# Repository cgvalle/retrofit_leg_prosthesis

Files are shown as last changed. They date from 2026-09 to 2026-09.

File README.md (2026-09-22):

# Retrofit Leg Prosthesis: EMG-controlled active add-on for a passive transfemoral prosthesis



Open hardware and software for a **retrofit module that gives a passive prosthetic knee (Ottobock 3R15) active flexion and extension**, driven by surface EMG from the residual limb.

This repository accompanies the manuscript *"From Passive to Active: An EMG-Controlled Add-On Module for Transfemoral Prostheses"*. It contains everything needed to rebuild the prototype that raced at the **CYBATHLON 2024 Powered Leg Prosthesis Race**.

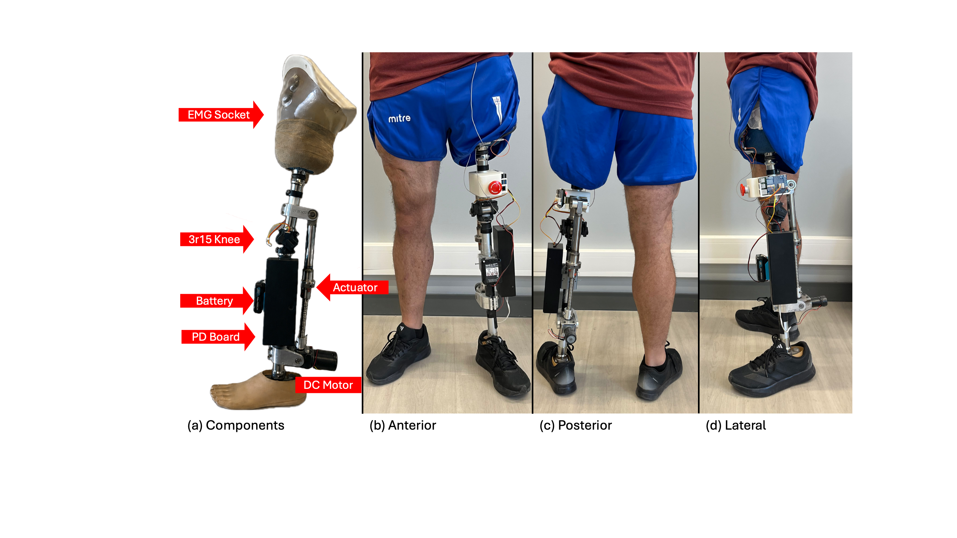
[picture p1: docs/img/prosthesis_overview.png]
Prosthesis overview


> [!WARNING]
> This is a **research prototype, not a medical device**. It was built and tested with a single user under supervision. It has no regulatory approval and must never be used without trained personnel, a reachable emergency stop and a clinician responsible for the socket fit. Read [docs/08_safety.md](docs/08_safety.md) before powering the motor.

## How it works

| Subsystem | Implementation |
|---|---|
| Host prosthesis | Ottobock 3R15 monocentric knee; the user's existing socket, pylons and foot are kept |
| Actuator | 12 V brushed DC worm-gear motor (5840-31ZY, 31:1) driving an SFU1610 ball screw (lead 10 mm) between thigh and shank attachment points. The worm gear is self-locking, so the knee holds its angle without power |
| Power | 12 V 1.5 Ah Li-ion pack (Makita 12 V max) → custom Power Distribution Board (LTC3780 12 V rail, LM2596 5 V rail, BTS7960 H-bridge, E-stop relay) |
| Sensing | 4-channel surface EMG (biceps femoris, rectus femoris, gluteus medius, adductor longus) with electrodes embedded in the socket, OpenBCI Cyton at 250 Hz; AS5600 magnetic encoder for the knee angle |
| Compute | One Raspberry Pi 4 runs everything: acquisition, filtering, Random-Forest intent classifier, knee-angle reference and the 100 Hz PID loop. The processes talk over a local MQTT broker (nanomq) |
| Control | Contraction → the knee reference flexes 5°; relaxation → it extends 5° (10 Hz, range 0–85°, 0 = extended). A predefined gait-pattern mode is also available |

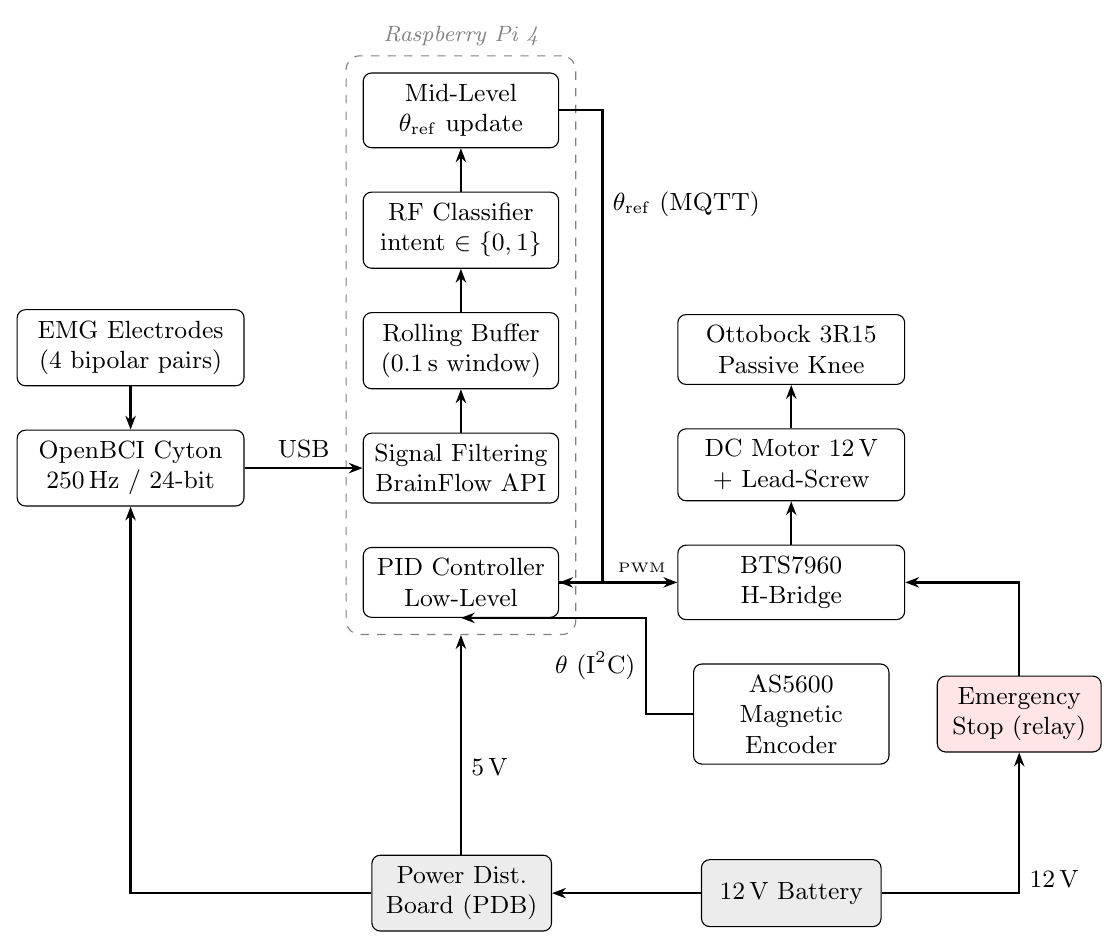
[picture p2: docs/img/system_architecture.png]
System architecture


## Repository layout

```
├── docs/                    Step-by-step build and operation guides (start here)
├── hardware/
│   ├── mechanical/          CAD (STEP / STL / Inventor), renders, motor-torque sizing
│   └── electronics/pdb/     Power Distribution Board: Gerbers, EasyEDA sources, BOM, schematic
├── software/                Python package `leg` that runs on the Raspberry Pi
│   ├── leg/io/stream.py             OpenBCI → filtered EMG → MQTT
│   ├── leg/models/train.py          Train the contract/relax Random Forest
│   ├── leg/models/realtime_inference.py   EMG-driven knee control
│   ├── leg/models/gait_csv_sender.py      Predefined gait-pattern control
│   ├── leg/models/motor_pid.py      AS5600 + BTS7960 PID position loop
│   ├── estimulos/test.py            Cue sequence for recording training data
│   └── test_code/                   Bench tests for motor, encoder and PID
└── analysis/                Metabolic-cost analysis notebook
```

## Build guide

1. [Bill of materials](docs/01_bill_of_materials.md)
2. [Mechanical build](docs/02_mechanical_build.md): mount the ball-screw actuator on the 3R15 knee
3. [Electronics](docs/03_electronics.md): fabricate and bring up the PDB, wire the Pi, motor, encoder and E-stop
4. [Raspberry Pi setup](docs/04_raspberry_pi_setup.md)
5. [EMG socket and acquisition](docs/05_emg_acquisition.md)
6. [Training the intent classifier](docs/06_training.md)
7. [Running the controller](docs/07_control.md)
8. [Safety checklist](docs/08_safety.md)
9. [Experimental protocol (metabolic evaluation)](docs/09_experimental_protocol.md)
10. [Known limitations and roadmap](docs/10_limitations_and_roadmap.md)

## Quick start (software only, no hardware)

```bash
cd software
python -m venv .venv && source .venv/bin/activate
pip install -r requirements.txt && pip install -e .
docker compose up -d                        # MQTT broker (nanomq) on localhost:1883
python -m leg.simulation.synthetic_stream   # BrainFlow synthetic board instead of the Cyton
python -m leg.models.realtime_inference --debug   # classifier only, no motor (needs a model.pkl)
```

## Citation

If you use this work, please cite the paper *"From Passive to Active: An EMG-Controlled Add-On Module for Transfemoral Prostheses"* (under review).

## Funding

Funded by ANID under grant CPS-RTC CIA250016.

## License

MIT: covers the software, hardware design files and documentation, provided "as is". See [LICENSE](LICENSE) and the medical [DISCLAIMER](DISCLAIMER.md).

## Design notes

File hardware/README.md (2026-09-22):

# Hardware

| Folder | Content |
|---|---|
| `mechanical/cad/step` | Machined actuator parts: motor adapter, ball-screw nut adapter, brackets D2/D3 |
| `mechanical/cad/stl` | Ball-screw nut adapter, rail connector, 3D-printed electronics box |
| `mechanical/cad/inventor` | Autodesk Inventor sources for the electronics box (vendor models of the Pi, bearing and button not included) |
| `mechanical/renders` | Preview images of the STL parts |
| `mechanical/sizing` | Motor-torque sizing: Mathematica notebook, PDF printout and Python port (`python torque_calculation.py` reproduces Table 1 of the paper) |
| `electronics/pdb` | Power Distribution Board: Gerbers, EasyEDA sources, BOM, schematic and layout images |

Build instructions: [docs/02_mechanical_build.md](../docs/02_mechanical_build.md) and [docs/03_electronics.md](../docs/03_electronics.md).

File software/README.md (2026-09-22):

# Software: `leg` package

Runs on a Raspberry Pi 4. Setup: [docs/04_raspberry_pi_setup.md](../docs/04_raspberry_pi_setup.md).

```bash
docker compose up -d                          # MQTT broker (nanomq)

python -m leg.io.stream                       # OpenBCI Cyton -> filtered EMG -> MQTT "data"
python -m leg.simulation.synthetic_stream     # same, from the BrainFlow synthetic board (no hardware)
python -m leg.plots.stream_plot               # live EMG plot

python -m leg.io.store_stream                 # record to recordings/<name>.npy
python -m estimulos.test                      # relax / contract cue sequence for training data
python -m leg.models.train <name> [<name> ...]   # train -> model.pkl

python -m leg.models.realtime_inference       # EMG-driven knee control (--debug: no motor)
python -m leg.models.gait_csv_sender          # predefined gait-pattern control (--debug: no motor)
```

| Path | Purpose |
|---|---|
| `leg/parameters.py` | MQTT host (`LEG_BROKER_HOST`), channel layout, sample rate |
| `leg/io/stream.py` | Cyton configuration, stateful 20–120 Hz band-pass + 50 Hz notch, auto-reconnect |
| `leg/models/features.py` | 9 features per channel (RMS, VAR, kurtosis, skewness, ZC, Hilbert-envelope mean/std/max/min) |
| `leg/models/split.py` | Windowing (25 samples) and train/test split |
| `leg/models/motor_pid.py` | AS5600 reading, encoder calibration, PID, BTS7960 drive (GPIO 13 / 18) |
| `test_code/` | Stand-alone bench tests for the encoder, motor direction, PWM and PID |
| `knee_angle_gait*.csv` | Reference trajectories for gait-pattern mode |

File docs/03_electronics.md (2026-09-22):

# 3. Electronics

## Power Distribution Board (PDB)

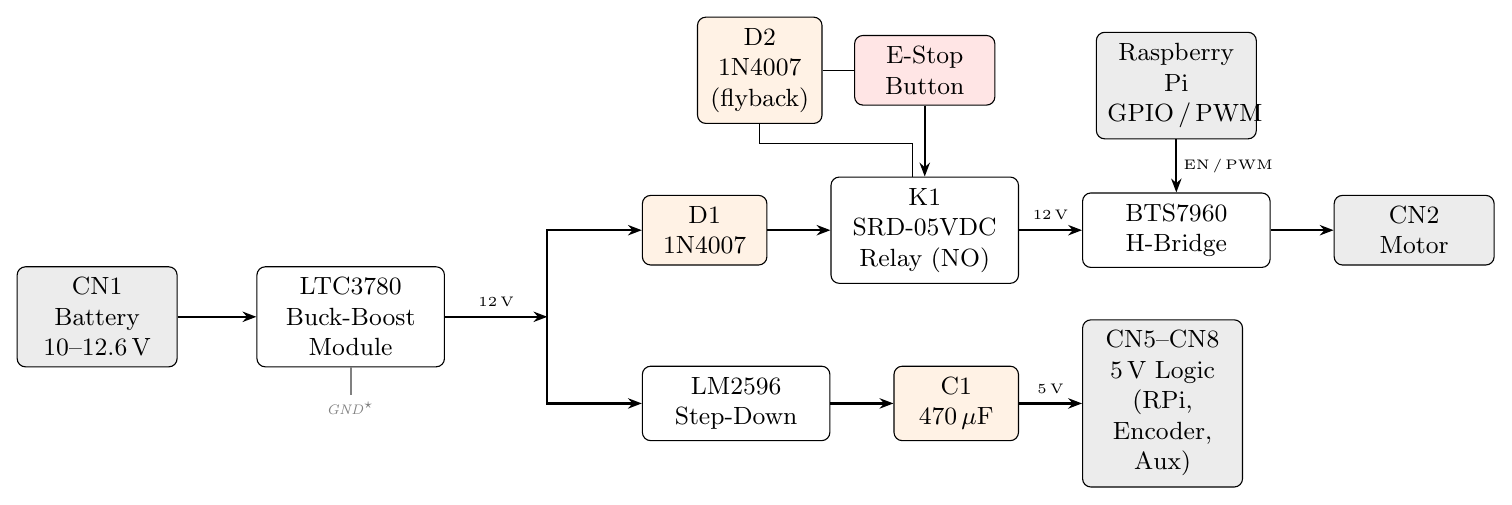
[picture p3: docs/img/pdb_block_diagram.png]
PDB block diagram


The PDB is a two-layer carrier board for off-the-shelf modules:

- **U1, LTC3780 buck-boost.** Turns the 10–12.6 V battery into a regulated **12 V** rail for the motor.
- **U2, LM2596 buck.** Steps the regulated 12 V down to the **5 V** logic rail (Raspberry Pi, encoder, BTS7960 logic).
- **U4, BTS7960 H-bridge.** Drives the motor (43 A peak; the board is operated at 5 A or less).
- **RLY1, SRD-05VDC relay.** Normally-open contact in the 12 V motor path. The E-stop button (CN9) opens it, which cuts motor power while the Pi stays on.
- **Protection.** 1N4007 flyback diode on the relay coil, a 1N4007 series diode on the 12 V motor line, 1 kΩ pull-downs on the PWM/IS lines (safe state at boot) and 1 kΩ pull-ups that keep R_EN/L_EN enabled.
- **Grounding.** Star ground: high-current motor returns and logic returns meet near the battery input.

Files in `hardware/electronics/pdb/`:

| File | Content |
|---|---|
| `gerber/PDB_gerber_2025-09-29.zip` | Fabrication files (upload as-is to JLCPCB or a similar service; 2 layers, 1.6 mm, default options) |
| `easyeda/PDB_schematic.json`, `easyeda/PDB_pcb.json` | Editable sources. In EasyEDA Std: *File → Open → EasyEDA…* and select the JSON |
| `PDB_BOM.csv` | Parts list |
| `PDB_schematic.png`, `PDB_layout_top.png`, `PDB_layout_bottom.png` | Quick-look images |

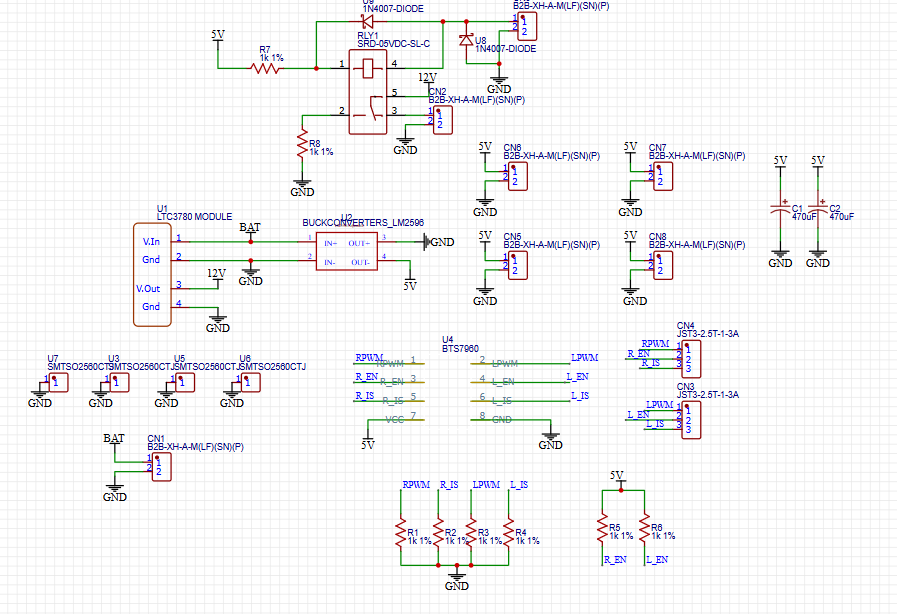
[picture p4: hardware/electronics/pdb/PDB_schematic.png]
PDB schematic


### Connectors

| Connector | Pins | Signal |
|---|---|---|
| CN1 | 1: +BAT, 2: GND | Battery input (10–12.6 V) |
| CN2 | 1: +12 V, 2: GND | Switched 12 V to the H-bridge / motor |
| CN3 | 1: LPWM, 2: L_EN, 3: L_IS | H-bridge control, left half |
| CN4 | 1: RPWM, 2: R_EN, 3: R_IS | H-bridge control, right half |
| CN5–CN8 | 1: +5 V, 2: GND | Logic outputs (Raspberry Pi, encoder, spare) |
| CN9 | 1: BTN IN, 2: BTN OUT | Emergency-stop button (drives the relay coil) |

### Bring-up (do this before connecting the Pi or the motor)

Use a bench supply set to 12 V with a 1 A current limit in place of the battery for steps 1–4.

1. Solder the modules and connectors. Before fitting the modules, check that there is no short between +BAT, +12 V, +5 V and GND.
2. Power CN1. Both module "on" LEDs should light. Adjust the **LTC3780** trimmer until its output reads **12.0 V**. If the output stays off, the undervoltage lock-out has tripped; adjust the trimmer closest to the battery input.
3. Adjust the **LM2596** to **5.0–5.1 V**. Check that the ripple is below 50 mVpp with C1/C2 fitted.
4. Press the E-stop and confirm there is **0 V on CN2**. Release it and confirm 12 V returns.
5. Connect the Raspberry Pi to a 5 V output and confirm it boots without brown-out (no lightning-bolt icon and no `Under-voltage detected` in `dmesg`).
6. Connect the H-bridge and the motor **with the actuator decoupled from the knee**, or with the knee held at mid-range. Run `software/test_code/motor_direction.py` and confirm both directions.
7. Load the motor at about 1 A and record the 12 V droop and module temperatures. Keep an eye on the BTS7960 heatsink.

## Wiring to the Raspberry Pi

| Signal | Pi pin (BCM) | Physical pin | Goes to |
|---|---|---|---|
| Motor PWM (20 kHz), **flexion** | GPIO 18 | 12 | H-bridge input that flexes the knee (RPWM or LPWM, whichever gives flexion on your build) |
| Motor PWM (20 kHz), **extension** | GPIO 13 | 33 | The other H-bridge input |
| I²C SDA | GPIO 2 | 3 | AS5600 SDA |
| I²C SCL | GPIO 3 | 5 | AS5600 SCL |
| 5 V in | — | 2 / 4 | PDB CN5 |
| GND | — | 6 | PDB CN5 GND (common with H-bridge GND) |
| USB | — | USB-A | OpenBCI RF dongle |

These pins are the ones in `software/leg/models/motor_pid.py` (`IN1 = 13`, `IN2 = 18`). A positive controller output (target angle above the measured angle, i.e. flex more) drives GPIO 18. If your knee moves the wrong way, swap the two PWM wires or the two motor leads. Do not swap the pins in software.

> [!CAUTION]
> The Pi's I²C lines are **3.3 V**. Many AS5600 breakouts have pull-up resistors to their own VCC. If you power the encoder from the 5 V rail, SDA and SCL will be pulled to 5 V. Either power the AS5600 from the Pi's **3.3 V** pin (physical pin 1) or remove the breakout's pull-ups.

## System wiring

System architecture

- The OpenBCI Cyton sends its data to the Pi through its USB RF dongle. In the paper's build it is powered from the PDB 5 V rail. The CYBATHLON 2024 build used a separate 6 V battery pack instead, which keeps the EMG front-end isolated from the motor supply; consider it if you see motor noise in the EMG.
- Keep the EMG leads away from the motor cables and the BTS7960. Intermittent drop-outs of the EMG stream were the most common failure seen during testing; connectors, cable routing and shielding all matter.

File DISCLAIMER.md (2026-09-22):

# Disclaimer

The MIT license in [LICENSE](LICENSE) covers the entire repository: software, hardware design files (CAD, PCB, BOM) and documentation.

This is a research prototype and **not a medical device**. It has no regulatory approval. Anyone who builds, modifies or uses it does so at their own risk. It must not be used on a person without trained supervision, a qualified prosthetist, an accessible emergency stop and appropriate ethics approval.

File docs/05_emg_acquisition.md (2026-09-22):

# 5. EMG socket and acquisition

## Muscles and channels

| Cyton channel | Muscle | Role |
|---|---|---|
| C1 | Biceps femoris (hamstrings) | Posterior thigh |
| C2 | Rectus femoris (quadriceps) | Anterior thigh |
| C3 | Gluteus medius | Hip abductor |
| C4 | Adductor longus | Hip adductor |

These are two agonist–antagonist pairs, one at the knee and one at the hip, that stay accessible after transfemoral amputation. In the paper's classifier, envelope features from **C3 (gluteus medius)** carried the most information.

## Electrode placement in the socket

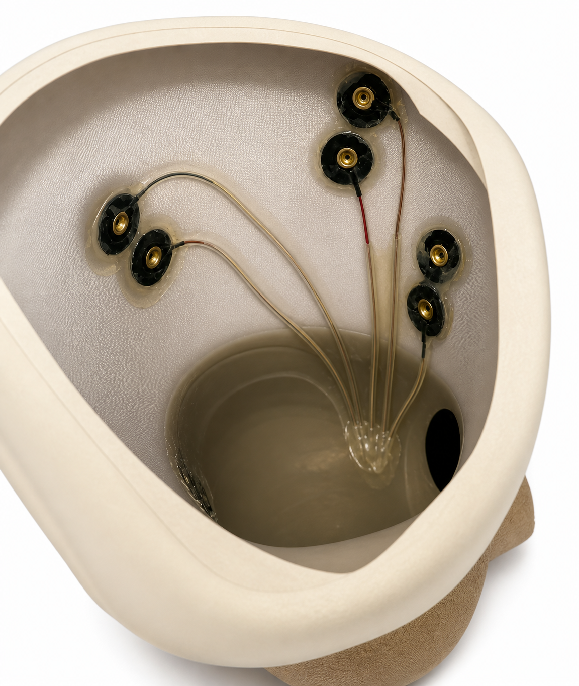
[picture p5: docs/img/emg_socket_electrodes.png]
Electrode placement


1. The clinical team finds the muscle bellies on the residual limb **before the socket is fabricated**.
2. For each muscle, embed two **gold cup electrodes** in the inner wall of the socket, **20 mm apart and aligned with the muscle fibres**.
3. Put one common reference electrode over an electrically quiet area at the hip.
4. Route the leads inside the socket wall to one connector on the socket, then to the Cyton.
5. Before every session, clean the skin with alcohol and put conductive paste on each cup.

> The socket must be made by a certified prosthetist. Embedding electrodes changes the socket's inner surface, so check fit and comfort with the user before any powered trial.

## OpenBCI configuration

`leg/io/stream.py` configures the Cyton at start-up through BrainFlow:

- **Bipolar** montage: gain ×24 (`gain_set=6`), normal electrode input, bias on, SRB2 off, SRB1 off.
- The serial port is auto-detected (the only `usb` device). Override it with `--serial-port /dev/ttyUSB0`.

Wiring:

| Electrode | Cyton pin |
|---|---|
| Muscle *n* (n = 1–4), electrode pair | Channel *n* **N** (bottom) and **P** (top) pins |
| Common reference at the hip | **BIAS** pin |

See the [OpenBCI Cyton documentation](https://docs.openbci.com/Cyton/CytonLanding/) for the header layout.

## Real-time filtering and features

`leg/io/stream.py` reads the board every 32 ms, removes a constant 2250 offset, and filters each EMG channel with **stateful** SOS filters, so block boundaries leave no artefacts:

- 4th-order Butterworth band-pass, **20–120 Hz**
- IIR notch at **50 Hz**, Q = 30 (change `self.mains` to 60 in countries with 60 Hz mains)

The filtered block goes out on the MQTT topic `data`. Features are then computed per 0.1 s window by `leg/models/features.py` (see [06](06_training.md)). If the packet counter stops advancing for 20 consecutive reads, the stream releases and re-opens the BrainFlow session. This recovers from the intermittent dongle drop-outs seen in testing.

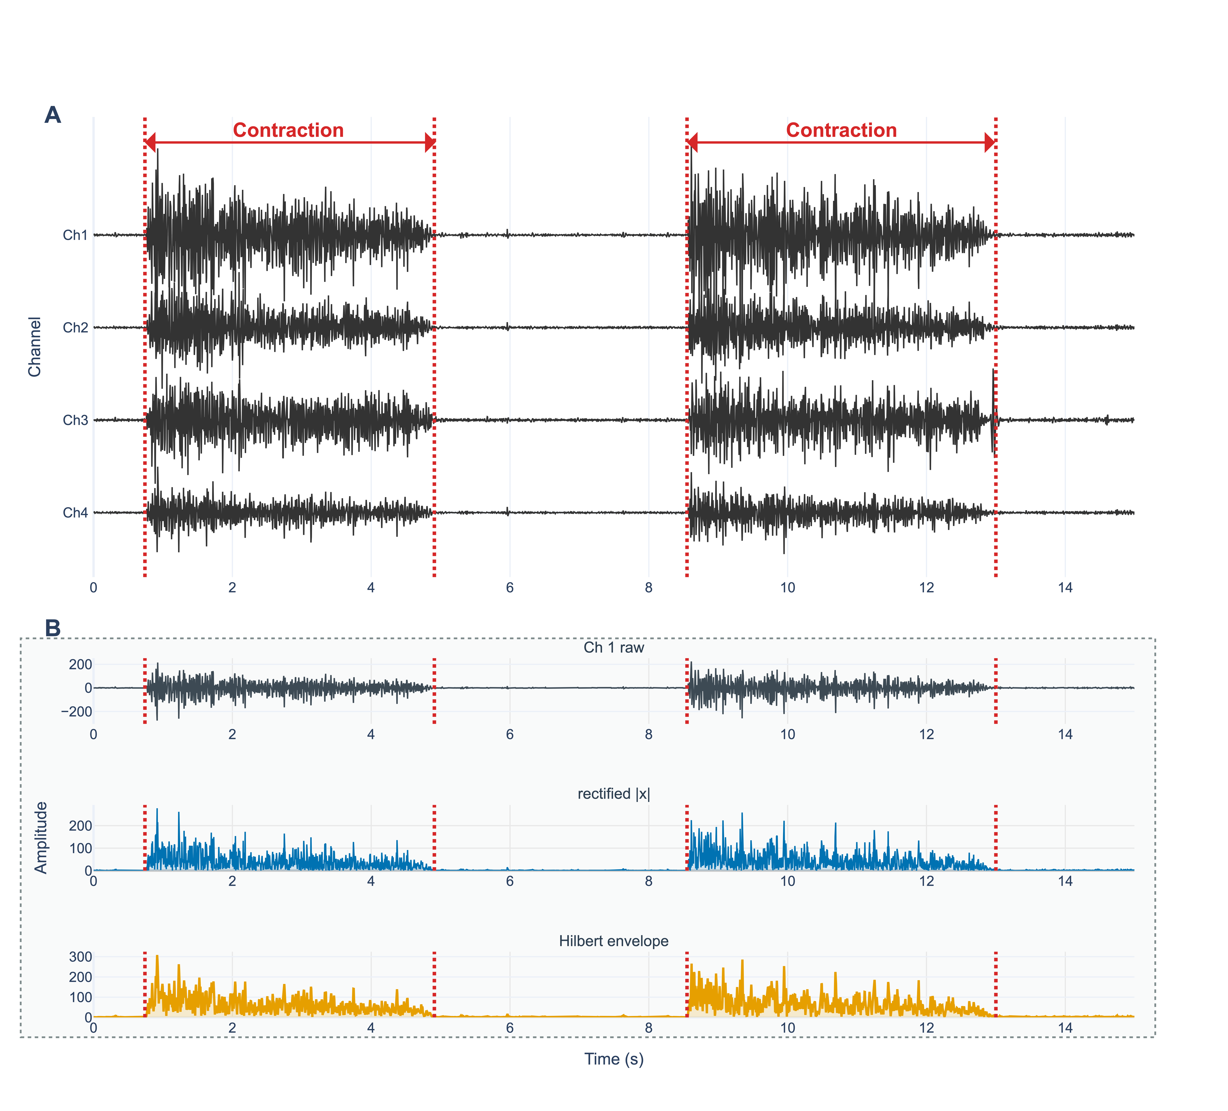
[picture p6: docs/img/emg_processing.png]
EMG processing


## Checking the signals

On a laptop on the same network:

```bash
export LEG_BROKER_HOST=retrofit-leg.local
python -m leg.plots.stream_plot
```

Ask the user to contract and relax. All four channels should show clear bursts. A flat or 50 Hz-dominated channel means poor contact; re-apply the paste or check the lead.

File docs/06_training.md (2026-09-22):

# 6. Training the intent classifier

The controller needs a binary classifier: **0 = relaxed**, **1 = voluntary contraction**. Train it for each user, and retrain whenever the electrodes are repositioned.

## 1. Record labelled data

Three terminals on the Pi, with the user seated and wearing the socket:

```bash
# Terminal 1: EMG stream
python -m leg.io.stream

# Terminal 2: recorder (asks for a file name, press q + Enter to stop)
python -m leg.io.store_stream          # e.g. name: user01_session01

# Terminal 3: cue sequence
python -m estimulos.test
```

`estimulos/test.py` publishes markers on the `marker` topic, and the stream writes them into the recording's marker channel:

- It starts with marker **0** (idle), then shows a 4 s countdown.
- Then come **20 trials of 4 s**, alternating **"Relaja!" (relax, marker 1)** and **"Contrae!" (contract, marker 2)**. The prompt is shown on screen; translate the strings in `estimulos/test.py` if needed.
- It ends with marker **0**.

Stop the recorder after the "Fin del experimento" message. The file is saved as `recordings/<name>.npy` with shape `(14, samples)`: EMG C1–C8, accelerometer, time, packet counter, marker.

Record several sessions: different days, and seated as well as standing. Trials recorded only while seated generalise poorly to walking.

## 2. Train

```bash
python -m leg.models.train user01_session01 user01_session02
```

`leg/models/train.py` then does the following:

1. Keeps samples with marker 1 or 2, and maps 2 → class 1 (contraction) and 1 → class 0 (rest).
2. Cuts channels **C1–C4** into non-overlapping **0.1 s windows (25 samples)**. 20 % of the windows are held out at random for testing (seed 42).
3. Extracts **9 features per channel, 36 in total**, with `leg.models.features_v1`: RMS, variance, kurtosis, skewness, zero-crossings, and the mean, standard deviation, max and min of the Hilbert envelope. Windows with invalid (NaN or inf) features are removed.
4. Fits a pipeline: **feature normalisation** (z-score) → **ANOVA F-score selection of the top 10 features** (`--k` to change) → **Random Forest**. The forest's hyperparameters are tuned by grid search (`n_estimators` 10–100, `max_depth` None/10/20, `min_samples_split` 2/5; 3-fold CV).
5. Prints the cross-validation and held-out accuracy, the confusion matrix, per-class precision/recall/F1, and the selected features ranked by importance.
6. Saves the whole pipeline to **`model.pkl`** in the current directory. It takes all 36 features as input, so the controller needs no changes when `--k` changes.

Run the controller from the same directory so it finds `model.pkl`.

## Expected performance

On the paper's pilot, 645 training and 161 test windows gave:

| | Predicted rest | Predicted contraction |
|---|---|---|
| True rest | 68 | 17 |
| True contraction | 10 | 66 |

That is **83.2 % accuracy**, with contraction precision 0.80, recall 0.87 and F1 0.83. Accuracy was 84.9 % on steady windows but only 55.6 % on windows at a rest↔contraction transition. Keeping the top 10 features gave 83.7 % cross-validation accuracy, against 84.7 % with all 36. Performance plateaus at about 10 features, and envelope-amplitude features from C3 (gluteus medius) dominate the selection.

If you get well below about 80 %, check electrode contact first (see [05](05_emg_acquisition.md)). Then check that the user is making a clear, repeatable contraction rather than a small one.

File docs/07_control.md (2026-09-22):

# 7. Running the controller

The control stack has three layers. Both operating modes share the same low-level loop.

```
High level  (10 Hz)   EMG window → features → Random Forest → intent ∈ {0, 1}
Mid level   (10 Hz)   intent → knee-angle reference θ_ref
Low level   (100 Hz)  PID → sign → BTS7960 at full duty (20 kHz PWM)
```

Knee angles run from **0° (fully extended) to 85° (flexed)**. See the encoder calibration in [04](04_raspberry_pi_setup.md).

## Mode A: EMG-driven intent control

```bash
docker compose up -d                        # broker, if not already running
python -m leg.io.stream                     # terminal 1
python -m leg.models.realtime_inference     # terminal 2 (model.pkl in the working directory)
```

To run the classifier without touching the motor (watch the reference on the `marker` topic), add `--debug`.

What `leg/models/realtime_inference.py` does:

- It keeps a rolling **0.1 s buffer** (25 samples) of C1–C4, fed by the `data` topic.
- Every **100 ms** it extracts the 36 features and passes them to the trained pipeline (normalisation → top-10 selection → Random Forest).
- **Contraction** raises the reference by **5°** (the knee flexes); **relaxation** lowers it by **5°** (the knee extends).
- Because the loop runs at 10 Hz, the reference slew rate is bounded at **50°/s** by construction, so abrupt setpoint changes cannot reach the low-level loop.
- The reference is clipped to **0–85°** and published on `marker` for logging.
- **Ctrl-C** sets the reference to 0° (fully extended) before exiting.

Piloting: the user learns to **contract to bend the knee and relax to straighten it**. Initiate motion *before* it is needed, since the actuator is slow. That anticipatory style worked for the Slopes and Wobbly Steps tasks at CYBATHLON.

## Mode B: predefined gait pattern

```bash
python -m leg.models.gait_csv_sender --speed 0.1 --n-samples 5 --log-csv run.csv
```

This mode plays back a knee-angle trajectory from `knee_angle_gait_short.csv` (default: 0° → 60° → 0°), resampled to `--n-samples` points. It advances one point every `1 / (10 × speed)` seconds and pauses 1.5 s between cycles. Every point is shifted by a hard-coded **−7°** (`angle -= 7`). Remove that line, or adjust the offset, for your build, because a negative target pushes the actuator against full extension. `--log-csv` saves target and measured angle over time. `knee_angle_gait.csv` holds a full normative gait-cycle profile (8–65°) that you can pass with `--csv`.

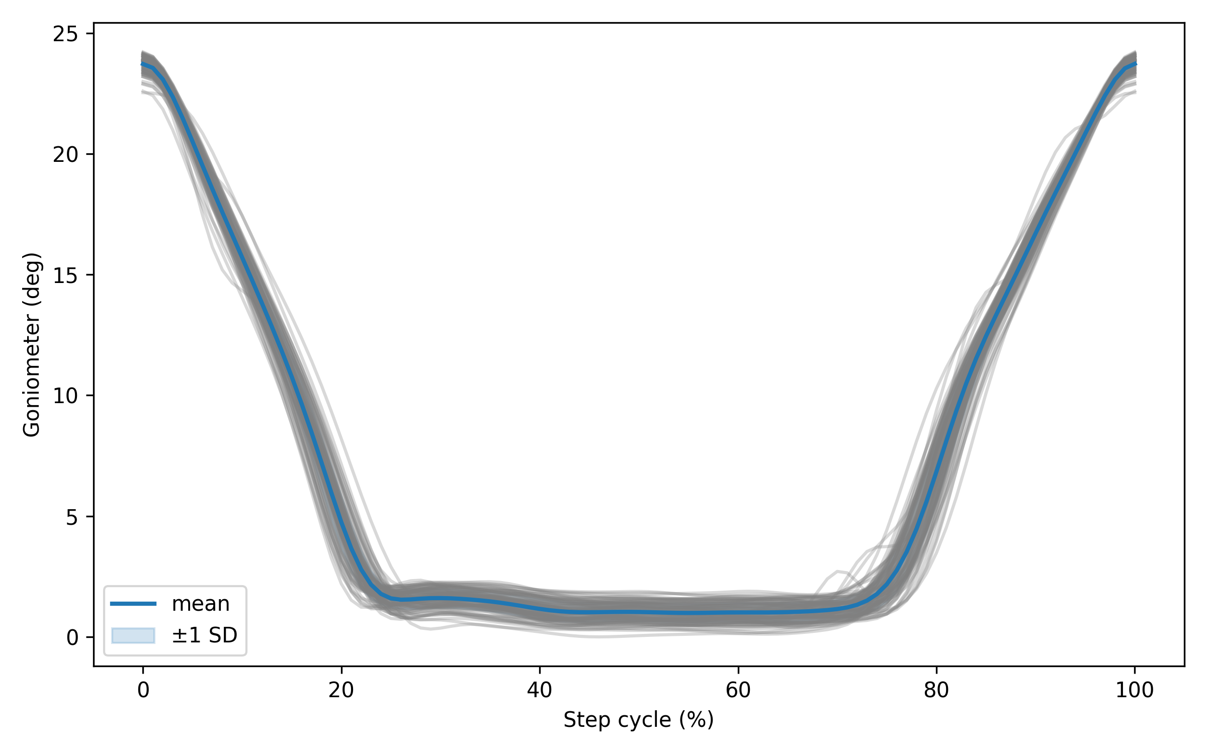
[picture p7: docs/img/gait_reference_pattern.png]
Reference gait pattern


## Low-level loop: `leg/models/motor_pid.py`

- Reads the AS5600 over I²C at **100 Hz** (12-bit, 0.088° per count) and converts it to the knee angle using the calibration constants.
- Discrete PID using the measured sample interval, so scheduling jitter does not bias the I and D terms. The integral is clamped to ±100, and the derivative term is skipped on the first sample after a reset.
- Gains (tuned on the bench): **Kp = 10, Ki = 0.1, Kd = 0.15**. Change them with `MotorPIDController(kp=…, ki=…, kd=…)`.
- **Drive law:** the sign of the PID output selects the direction. A positive output drives GPIO 18 (flexion) and a negative output drives GPIO 13 (extension), at **100 % duty** with **20 kHz PWM**. The other input is held at 0. Because the screw is highly reduced and non-back-drivable, the switching does not reach the joint as abrupt motion. The cost is a small limit cycle around the reference.

## Monitoring

From a laptop: `LEG_BROKER_HOST=retrofit-leg.local python -m leg.plots.stream_plot` shows the EMG channels live, and the marker channel shows the knee reference. `python -m leg.io.store_stream` records everything to `.npy` for later analysis.

## Performance to expect

- Walking assistance works on a treadmill at about **1 km/h**; tracking degrades when the reference changes quickly.
- Stairs, obstacle clearance and high steps were **not** achievable with this actuator and binary control (see [10](10_limitations_and_roadmap.md)).

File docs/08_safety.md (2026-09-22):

# 8. Safety

This device moves a joint that a person is standing on. Treat every powered session as a clinical experiment: get ethics approval, have a prosthetist and an engineer present, and use a harness or parallel bars for early trials.

## Failure behaviour you must know

| Situation | What happens | Mitigation |
|---|---|---|
| E-stop pressed | The relay cuts the 12 V motor supply. The Pi keeps running. **The knee locks at its current angle** (the worm gear is self-locking) | Train the user and the assistant to press it. Test it at the start of every session |
| Battery empty or power lost | Same as the E-stop: the knee locks where it is. The passive 3R15 cannot swing | Check the charge (Makita gauge) before each session; one battery lasts about 2.5 h of walking |
| EMG stream stalls (dongle drop-out) | `leg.io.stream` tries to re-open the session, but **the inference keeps classifying the last buffer**, so the reference can drift to a limit | Watch the live plot and keep the E-stop ready. Adding a watchdog is on the roadmap |
| Control process crashes | Ctrl-C drives the knee to full extension, but an unhandled crash can leave a PWM pin in its last state | Keep the E-stop reachable. Bench-test after every software change |
| Misclassification | Each false prediction moves the reference 5° the wrong way (at most 50°/s) | Start with the prosthesis off the user, then in parallel bars |

## Before every session

- [ ] Battery charged; E-stop tested (0 V on the motor with the button pressed)
- [ ] All actuator fasteners and the screw coupling checked; no play at the nut or supports
- [ ] Encoder reads 0° at full extension and tracks flexion correctly up to 85° (`test_code/encoder.py`)
- [ ] Classifier trained or validated **today** with the electrodes as placed (see [06](06_training.md))
- [ ] Live EMG looks clean on all four channels
- [ ] Controller run in `--debug` mode first: the reference follows contract/relax as expected
- [ ] First motor movements done with the user seated and the foot off the ground

## Electrical

- Use a bench supply with current limiting for the first PDB power-up.
- The BTS7960 can source tens of amps. Watch its temperature under sustained load, and fuse the battery line.
- Li-ion packs: use the original charger, never charge unattended, and keep the pack in its impact-resistant case.

## Mechanical

- The actuator adds about 4 kg, mostly distal, which the user feels during fast leg movements.
- Check the ball screw's travel at both ends. At full extension the nut must not bottom out, because the motor has no end-stop sensing in the current software.

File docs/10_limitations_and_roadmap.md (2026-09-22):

# 10. Known limitations and roadmap

## Limitations of this prototype

- **Actuator authority.** The 5840-31ZY motor gives 0.49 N·m, but level walking needs 0.77–1.53 N·m (`hardware/mechanical/sizing`). Assistance is partial, and fast tasks (stairs, obstacle clearance, high steps, sit-to-stand) are out of reach. At CYBATHLON 2024 only Slopes (both runs) and Wobbly Steps (run 2) were completed.
- **Non-back-drivable transmission.** It holds position without power, but it removes free pendular swing, so all knee motion has to come from the torque-limited motor.
- **Binary intent.** Contract/relax commands only change the reference in steps. There is no proportional control of speed, torque or impedance, and no automatic gait-phase detection.
- **EMG robustness.** Intermittent drop-outs of the OpenBCI stream were seen, with no conclusive cause. The classifier was validated offline on static trials (83.2 %), not during walking.
- **Mass.** The module adds about 4 kg, mostly distal, for a total of about 8 kg.
- **Evidence.** Everything was tested with a single participant.

## Software to-dos

- Watchdog: stop the motor if no EMG packet arrives within about 200 ms.
- End-of-travel protection: stall-current sensing through the BTS7960 `IS` pins, or limit switches.
- Soft-start PWM ramps. The driver currently switches straight to 100 % duty.

## Hardware roadmap (CPS-RTC internal design review, 2026)

- Battery: move from the 3S Li-ion Makita pack (16.2 Wh, 1–2 C) to a 4S LiPo (22.2 Wh, 35 C) with an external BMS and XT60 connector. The LTC3780 then runs in buck mode (≈95–96 % efficiency).
- Motor: a candidate is the maxon RE 30 (60 W, 12 V, 87 % peak efficiency) with a GP32 A planetary gearhead. Its high start-up current (about 61 A) needs a PWM soft start over 30–50 ms, because the 12 V rail is limited to 8–10 A. The review also recommends moving to a BLDC motor with a matching three-phase driver.
- Characterise the torque–speed demand of the knee for each task before choosing the next actuator.
- Mount the motor at the knee to reduce distal mass.
- Environment sensing (2D LiDAR, IMU) for terrain-aware control.

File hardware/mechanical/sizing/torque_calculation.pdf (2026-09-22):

# Cálculos torque-motor para caminata

# 1. Lados triángulos naranjos (fijos)

In[ ]:= a1 = 90;
k1 = 295;
a2 = 50;
k2 = 50;

# 2. Lados triangulo principal

In[ ]:= bmin = 275;
bmax = 385;
k =
raíz cuadrada

Sqrt[k1^2 + k2^2] //
valor numérico

N

a =
raíz cuadrada

Sqrt[a1^2 + a2^2] //
valor numérico

N

Out[]= 299.207

Out[]= 102.956

# 3. Ángulos triángulos naranjos (fijos)

In[ ]:= sola =
resuelve

Solve[a2^2 a1^2 + a^2 - 2 * a1 * a * coseno

Cos[x] && 0 < x <
número pi

Pi, x] //
valor numérico

N

a3 = (x /.
primero

First[sola]) /
grado

Degree //
valor numérico

N

Solve: Solve was unable to solve the system with inexact coefficients. The answer was obtained by solving a corresponding exact system and numericizing the result.

Out[]= {{x 0.507099}}

Out[]= 29.0546

Printed by Wolfram Mathematica Student Edition

In[ ]:= solk =
resuelve

Solve[k2^2 k1^2 + k^2 - 2 * k1 * k * coseno

Cos[x] && 0 < x <
número pi

Pi, x];

k3 = (x /.
primero

First[solk]) /
grado

Degree //
valor numérico

N

Solve: Solve was unable to solve the system with inexact coefficients. The answer was obtained by solving a corresponding exact system and numericizing the result.

Out[]= 9.61973

# 4. Ángulo rodilla máximo con largo husillo mínimo (no usar)

In[ ]:= sol =
resuelve

Solve[bmin^2 a^2 + k^2 - 2 * a * k * coseno

Cos[x] && 0 < x <
número pi

Pi, x] //
valor numérico

N;

beta = (x /.
primero

First[sol]) /
grado

Degree //
valor numérico

N

Solve: Solve was unable to solve the system with inexact coefficients. The answer was obtained by solving a corresponding exact system and numericizing the result.

Out[]= 66.5681

In[ ]:= alfa = 180 - beta - a3 - k3

Out[]= 74.7576

# 5. Ángulo rodilla mínimo con largo husillo máximo

In[ ]:= sol =
resuelve

Solve[bmax^2 a^2 + k^2 - 2 * a * k * coseno

Cos[x] && 0 < x <
número pi

Pi, x] //
valor numérico

N;

beta = (x /.
primero

First[sol]) /
grado

Degree //
valor numérico

N

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

Out[]= 141.326

In[ ]:= alfa = 180 - beta - a3 - k3
Out[]= -4.9738 × 10⁻¹⁴

# 6. Largo husillo con ángulo rodilla literatura (desde acá probar ángulos)

In[ ]:= alfa = 1;

In[ ]:= beta = -alfa + 180 - a3 - k3

Out[]= 140.326

### 2 calculos v2.nb

In[ ]:= sol =
resuelve

Solve[x^2 a^2 + k^2 - 2 * a * k * coseno

Cos[beta °] && x > 0, x] // valor numérico

N;

b = (x /.
primero

First[sol]) //
valor numérico

N

Out[]= 384.117

# 7. Vectores posición

In[ ]:= K = {0, 0, 0};
A = {-a2, a1, 0};
B = {-k2 *
coseno

Cos[alfa °] - k1 *
seno

Sin[alfa °], k2 *
seno

Sin[alfa °] - k1 *
coseno

Cos[alfa °], 0} //
valor numérico

N

Out[]= {-55.1408, -294.082, 0.}

In[ ]:= KA = A - K
KB = B - K
AB = B - A

Out[]= {-50, 90, 0}

Out[]= {-55.1408, -294.082, 0.}

Out[]= {-5.14084, -384.082, 0.}

# 8. Brazo palanca (P = peso, M = momento extensor, r = brazo, F = fuerza)

In[ ]:= c = 0.49;
P = 90.36;

In[ ]:= M = c * P
r =
norma

Norm[
producto vectorial

Cross[KA, KB]] /
norma

Norm[AB] / 1000 //
valor numérico

N

F = M / r

Out[]= 44.2764

Out[]= 0.0512

Out[]= 864.773

# 9. Torque motor (L = paso hilo, e = eficiencia)

In[ ]:= L = 0.01;
e = 0.9;

In[ ]:= T = (F * L) / (2 *
número pi

Pi * e)

Out[]= 1.52925

calculos v2.nb 3

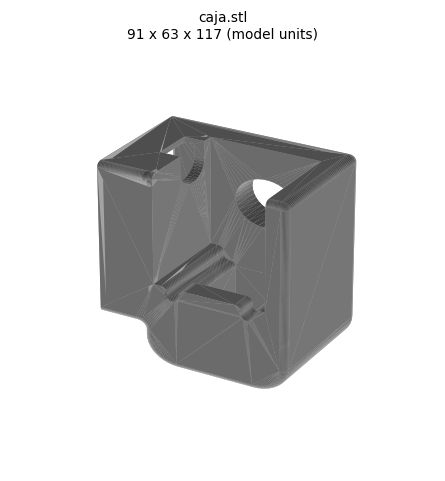
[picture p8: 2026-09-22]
hardware/mechanical/renders/electronics_box.png

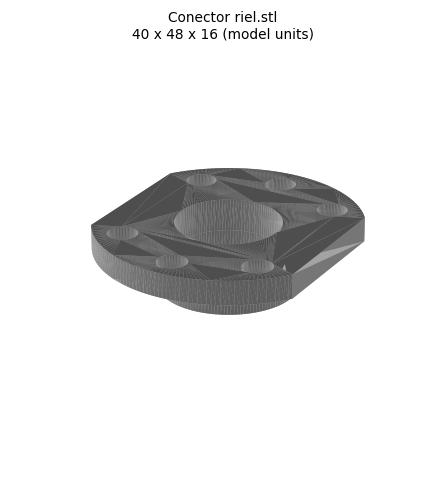
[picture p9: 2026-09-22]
hardware/mechanical/renders/rail_connector.png

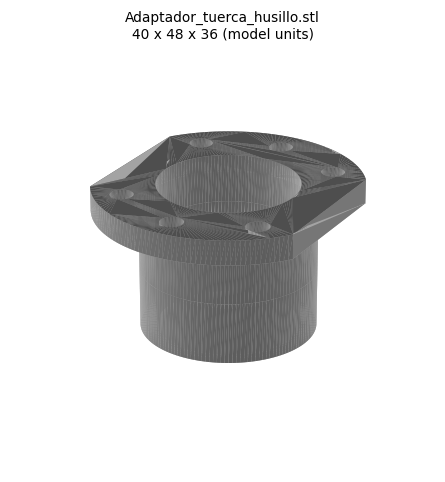
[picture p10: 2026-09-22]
hardware/mechanical/renders/ballscrew_nut_adapter.png

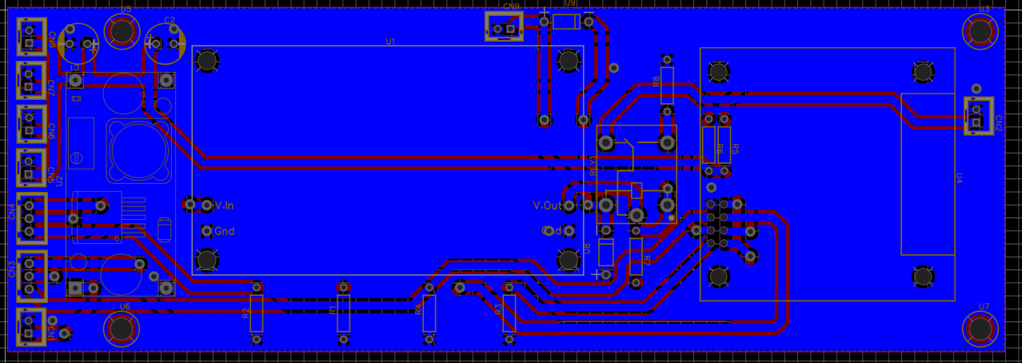
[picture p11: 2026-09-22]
hardware/electronics/pdb/PDB_layout_bottom.png

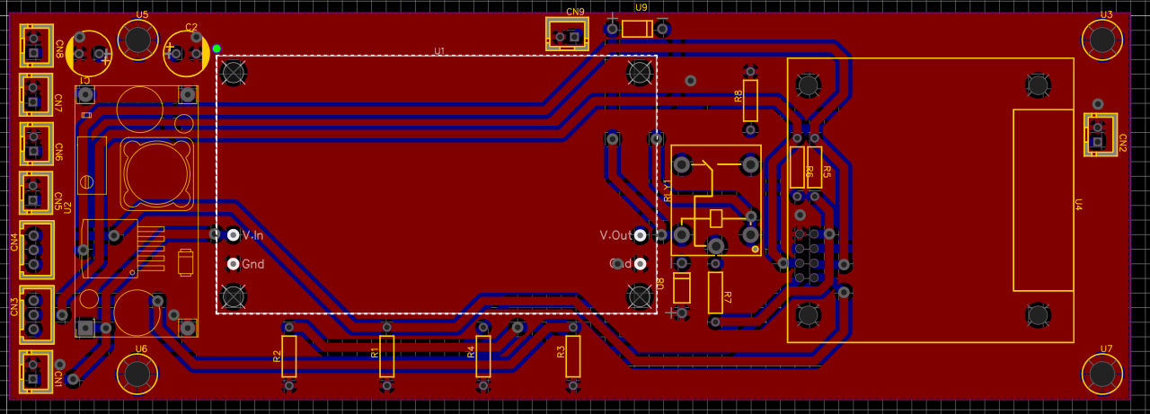
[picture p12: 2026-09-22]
hardware/electronics/pdb/PDB_layout_top.png

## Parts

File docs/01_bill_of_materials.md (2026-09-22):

# 1. Bill of materials

Quantities are for one prosthesis. The table assumes the user already has a prescribed passive prosthesis built around an **Ottobock 3R15** knee. The add-on keeps that socket, knee, pylons and foot.

Items marked **TBD** could not be confirmed from the project records; measure them on your build.

## Host prosthesis (already prescribed to the user)

| Item | Qty | Notes |
|---|---|---|
| Ottobock 3R15 monocentric knee joint | 1 | Steel, 490 g, max. user mass 100 kg, flexion up to 150° |
| Custom socket | 1 | Made by the user's prosthetist. The EMG electrodes are embedded in its inner wall (see [05](05_emg_acquisition.md)) |
| Upper tube / stem | 1 | Aluminium, Ø 32.4 mm, 120 mm long (CYBATHLON 2024 build) |
| Lower tube / stem | 1 | Aluminium, Ø 32.4 mm, 320 mm long (CYBATHLON 2024 build) |
| Prosthetic foot and pyramid adapters | 1 set | Whatever the user already wears |

## Actuator

| Item | Qty | Notes |
|---|---|---|
| Brushed DC worm-gear motor, 12 V, **5840-31ZY**, 200 rpm variant (31:1) | 1 | 0.49 N·m nominal at 200 rpm, 2 A, 364 g. The worm gear is **self-locking**. See the torque note below |
| Ball-screw kit **SFU1610** (Ø16 mm, lead 10 mm, C5) with **BK12** fixed and **BF12** floating supports and a nut | 1 | Sold as a kit, cut to length. The prototype screw spans 294–384 mm between attachment points |
| Shaft coupling, motor → screw | 1 | Set-screw adapter, sized to the motor output shaft |
| Motor adapter (machined) | 1 | `hardware/mechanical/cad/step/motor_adapter.step` |
| Ball-screw nut adapter | 1 | `hardware/mechanical/cad/step/ballscrew_nut_adapter.step` (STL also provided) |
| Rail connector | 1 | `hardware/mechanical/cad/stl/rail_connector.stl` |
| Brackets D2 / D3 | 1 each | `hardware/mechanical/cad/step/D2.step`, `D3.step`, `D3_v2.step` |
| Fasteners (M3–M6), spacers | TBD | Depends on your knee and tube clamps |

> **Torque note.** The installed motor is **under-sized**: level walking needs 0.77–1.53 N·m at the motor shaft (see `hardware/mechanical/sizing/torque_calculation.py`), but the motor gives 0.49 N·m. The prototype therefore provides only partial assistance. If you are rebuilding the device, consider a stronger drive (see [10](10_limitations_and_roadmap.md)).

## Electronics

| Item | Qty | Notes |
|---|---|---|
| Raspberry Pi 4 Model B (2 GB or more) + microSD card (16 GB or more) | 1 | Runs all software |
| OpenBCI Cyton (8-ch, 250 Hz, 24-bit) + USB RF dongle | 1 | Only channels C1–C4 are used for control |
| AS5600 magnetic angle encoder breakout + diametric magnet | 1 | I²C address 0x36, 12-bit |
| Power Distribution Board (PDB) | 1 | Custom PCB. See `hardware/electronics/pdb/PDB_BOM.csv` for its parts (LTC3780, LM2596 and BTS7960 modules, SRD-05VDC relay, etc.) |
| Emergency-stop push button, self-locking (e.g. LAY37 series) | 1 | Wired to PDB connector CN9. Cuts **only** the motor supply |
| Battery: Makita 12 V max Li-ion, 1.5 Ah (3S, 10.8 V nominal) | 1–2 | About 2.5 h of walking per charge. Needs a Makita battery-slot adapter with a keyed connector |
| 3D-printed electronics box | 1 | `hardware/mechanical/cad/stl/electronics_box.stl` (91 × 63 × 117 mm). Holds the Pi and the E-stop |
| JST-XH 2.5 mm housings and crimp contacts, silicone wire (18 AWG for the motor, 24 AWG for signals) | — | |

## EMG consumables

| Item | Qty | Notes |
|---|---|---|
| Gold cup electrodes | 9 | 4 bipolar pairs + 1 common reference at the hip |
| Conductive paste (e.g. Ten20) | — | |
| Isopropyl alcohol wipes | — | Clean the skin before donning |

## Tools

- Access to a CNC mill or lathe, or a machining service, for the metal adapters.
- FDM 3D printer (PETG or ABS) for the electronics box.
- Soldering station and multimeter; a bench supply with current limit is strongly recommended for bring-up.
- PCB fabrication service (the Gerbers are ready for JLCPCB).

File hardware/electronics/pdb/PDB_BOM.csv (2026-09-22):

designator | qty | part | value_or_mpn | footprint | notes
U1 | 1 | LTC3780 buck-boost module | LTC3780 module | module | Regulated 12 V motor/logic rail from 10-12.6 V battery; set output to 12.0 V with trimmer before connecting loads
U2 | 1 | LM2596 step-down module | LM2596 module | module | 5 V logic rail (Raspberry Pi 4 + AS5600 + BTS7960 logic); fed from the regulated 12 V rail; set to 5.0-5.1 V before connecting the Pi
U4 | 1 | BTS7960 H-bridge module | BTS7960 (IBT-2) module | module | Motor driver; RPWM/LPWM from Pi GPIO
RLY1 | 1 | Relay 5 V coil SPDT | SRD-05VDC-SL-C | RELAY-TH_SRD-XXVDC-XL-C | Normally-open contact in the 12 V motor path; opened by the E-stop button
C1 | 1 | Electrolytic capacitor | 470 uF 25 V (25ZLH470MEFCT78X16) | CAP-TH_BD8.0-P3.50 | Bulk on 5 V rail
C2 | 1 | Electrolytic capacitor | 470 uF 25 V (25ZLH470MEFCT78X16) | CAP-TH_BD8.0-P3.50 | Bulk on 5 V rail
U8 | 1 | Rectifier diode | 1N4007 | DO-41 | Flyback / relay coil protection
U9 | 1 | Rectifier diode | 1N4007 | DO-41 | Series blocking diode on 12 V motor line
R1-R4 | 4 | Resistor | 1 kOhm 1% | THT | Pull-downs on RPWM / R_IS / LPWM / L_IS (safe state at boot)
R5-R6 | 2 | Resistor | 1 kOhm 1% | THT | Pull-ups to 5 V on R_EN / L_EN (bridge always enabled)
R7-R8 | 2 | Resistor | 1 kOhm 1% | THT | Relay coil drive network (E-stop)
CN1 | 1 | JST XH 2-pin | B2B-XH-A-M | 2.5 mm | Battery input (+12 V / GND)
CN2 | 1 | JST XH 2-pin | B2B-XH-A-M | 2.5 mm | 12 V out to motor driver
CN3 | 1 | JST 3-pin | JST3-2.5T-1-3A | 2.5 mm | LPWM / L_EN / L_IS
CN4 | 1 | JST 3-pin | JST3-2.5T-1-3A | 2.5 mm | RPWM / R_EN / R_IS
CN5-CN8 | 4 | JST XH 2-pin | B2B-XH-A-M | 2.5 mm | +5 V / GND logic outputs (Pi / encoder / aux)
CN9 | 1 | JST XH 2-pin | B2B-XH-A-M | 2.5 mm | E-stop button in / out (relay coil control)
U3 U5 U6 U7 | 4 | SMD standoff M2.5 | SMTSO2560CTJ | SMD | Module mounting standoffs

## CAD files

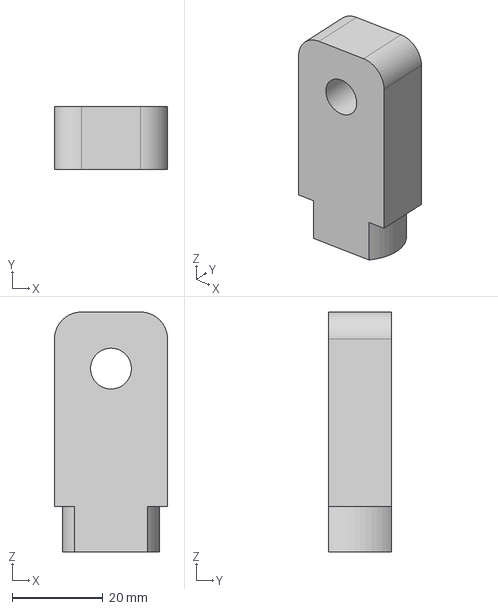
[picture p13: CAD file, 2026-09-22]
hardware/mechanical/cad/step/D3_v2.step
25.0 x 14.0 x 53.0 mm

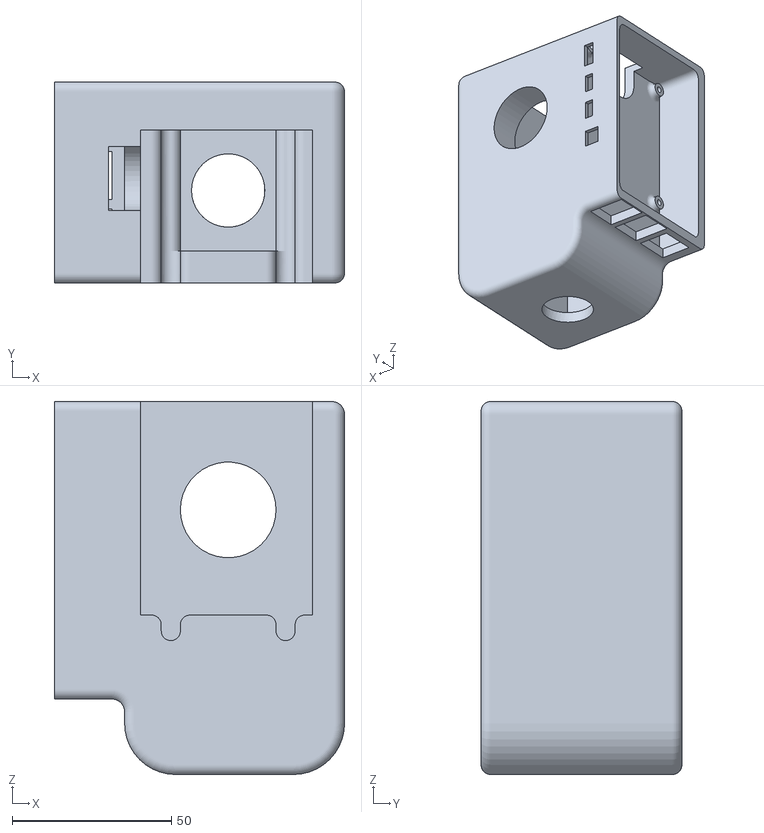
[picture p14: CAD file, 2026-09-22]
hardware/mechanical/cad/stl/electronics_box.stl
91.0 x 63.0 x 117.0

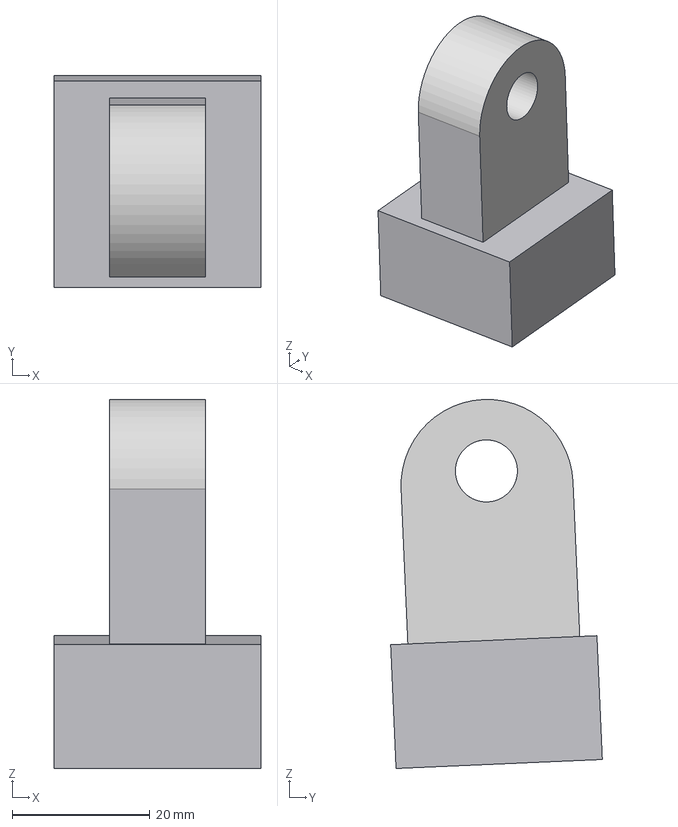
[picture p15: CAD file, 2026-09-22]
hardware/mechanical/cad/step/D2.step
30.0 x 30.8 x 53.6 mm

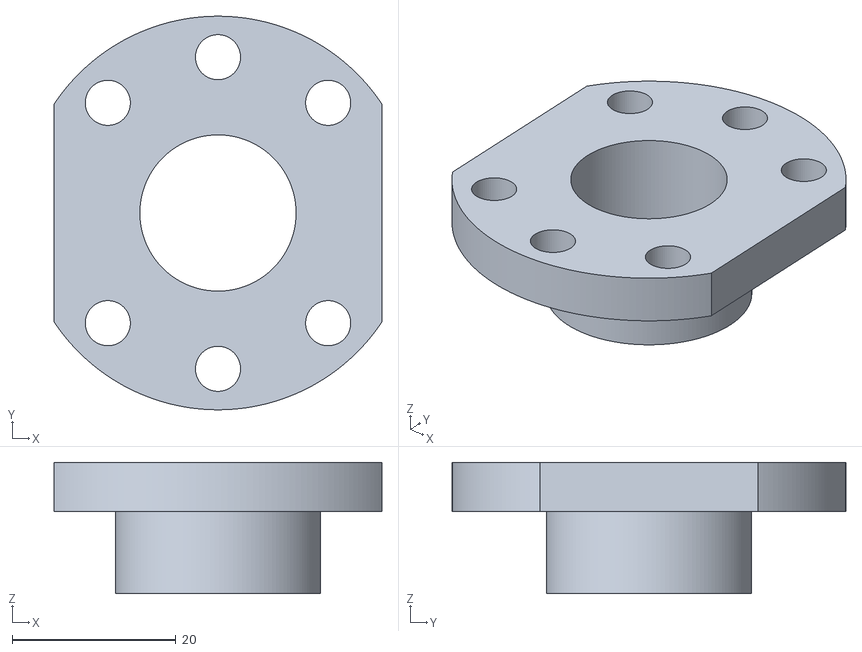
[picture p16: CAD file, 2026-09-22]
hardware/mechanical/cad/stl/rail_connector.stl
40.0 x 48.0 x 16.0

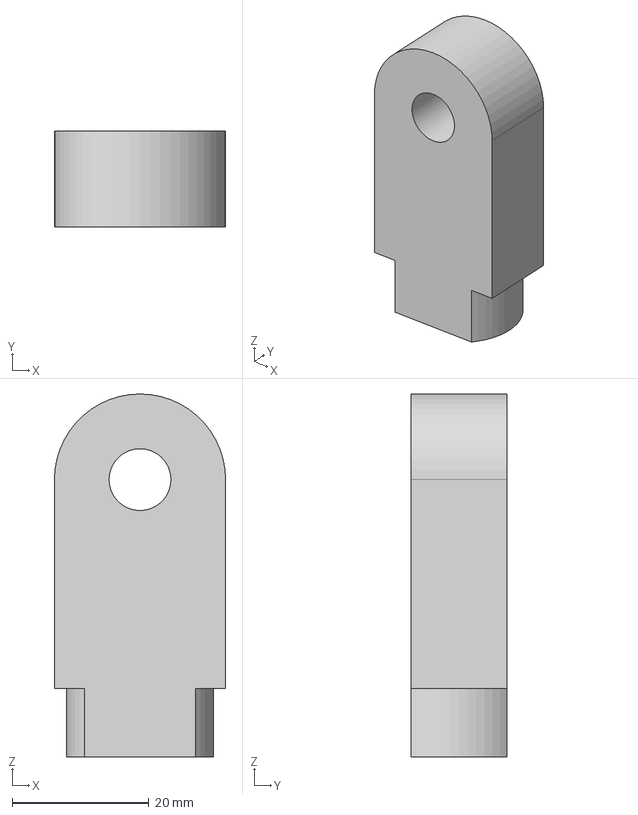
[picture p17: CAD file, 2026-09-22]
hardware/mechanical/cad/step/D3.step
25.0 x 14.0 x 53.0 mm

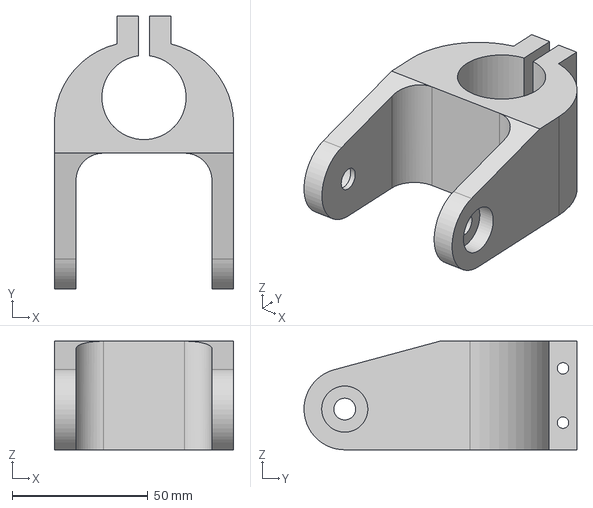
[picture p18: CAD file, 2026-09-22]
hardware/mechanical/cad/step/motor_adapter.step
66.0 x 100.5 x 40.0 mm

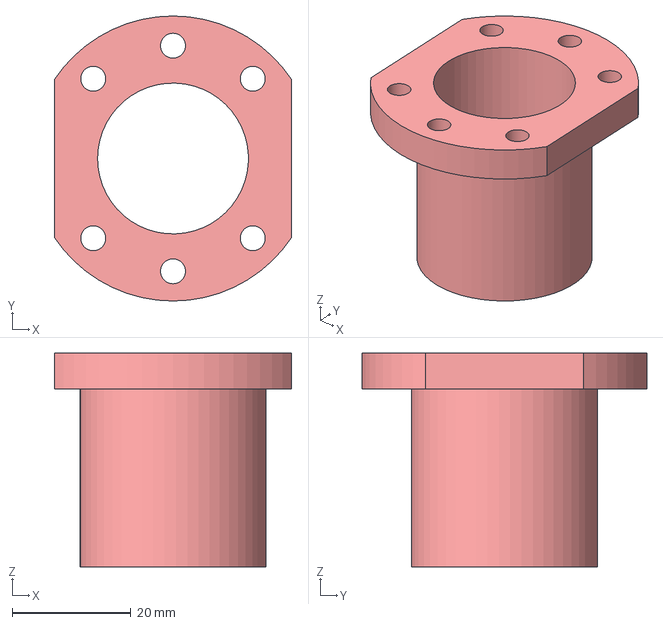
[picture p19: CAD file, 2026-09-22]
hardware/mechanical/cad/step/ballscrew_nut_adapter.step
40.0 x 48.0 x 36.0 mm

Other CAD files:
hardware/mechanical/cad/inventor/Part4.ipt
hardware/mechanical/cad/inventor/base.ipt
hardware/mechanical/cad/inventor/bot_L.ipt
hardware/mechanical/cad/inventor/bot_R.ipt
hardware/mechanical/cad/inventor/caja_potencia.ipt
hardware/mechanical/cad/inventor/raspi.iam
hardware/mechanical/cad/inventor/top_.ipt
hardware/mechanical/cad/stl/ballscrew_nut_adapter.stl

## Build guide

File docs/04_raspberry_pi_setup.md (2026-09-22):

# 4. Raspberry Pi setup

All the software runs on one Raspberry Pi 4. The processes exchange data through an MQTT broker (nanomq) on the same Pi. The broker also lets a laptop on the same network watch the signals live.

## 1. Operating system

1. Flash **Raspberry Pi OS Lite (64-bit)** with Raspberry Pi Imager.
2. In the Imager's advanced options, set the hostname (e.g. `retrofit-leg`), create a user, enter your Wi-Fi details and **enable SSH**.
3. Boot, SSH in, and update:

```bash
sudo apt update && sudo apt full-upgrade -y
sudo apt install -y git python3-venv python3-dev i2c-tools
```

## 2. Enable I²C and hardware access

```bash
sudo raspi-config nonint do_i2c 0      # enable I2C
sudo usermod -aG gpio,i2c,dialout $USER
sudo reboot
```

With the encoder connected, `i2cdetect -y 1` should show a device at **0x36**.

> The motor code uses `RPi.GPIO`, which works on the Raspberry Pi 4. It does **not** work on a Raspberry Pi 5.

## 3. Install the software

```bash
git clone https://github.com/cgvalle/retrofit_leg_prosthesis.git && cd retrofit_leg_prosthesis/software
python3 -m venv .venv && source .venv/bin/activate
pip install -r requirements.txt
pip install -e .
```

**BrainFlow** is the library that talks to the OpenBCI board. If `pip install brainflow` does not ship working ARM64 binaries for your OS version (`python -c "from brainflow.board_shim import BoardShim"` fails), build it from source:

```bash
sudo apt install -y cmake build-essential libboost-all-dev
git clone https://github.com/brainflow-dev/brainflow.git && cd brainflow
mkdir build && cd build && cmake .. && make -j4 && sudo make install
cd ../python_package && pip install .
```

## 4. MQTT broker

Install Docker ([official instructions for Debian](https://docs.docker.com/engine/install/debian/)), then:

```bash
cd retrofit_leg_prosthesis/software
docker compose up -d          # starts nanomq on port 1883 (restarts on boot)
```

MQTT topics used:

| Topic | Payload | Producer → consumer |
|---|---|---|
| `data` | float32 array, shape (14, N): 8 EMG, 3 accel, time, packet, marker | `leg.io.stream` → inference, recorder, plots |
| `marker` | integer. During training: 0 = idle, 1 = relax, 2 = contract. During control: the current knee-angle reference | `estimulos/test.py` or the controllers → `leg.io.stream` (stored in the marker channel) |

The broker host defaults to `127.0.0.1`. To run a process on another machine (e.g. the live plot on a laptop), set `export LEG_BROKER_HOST=retrofit-leg.local`.

## 5. Bench tests

Run these with the actuator **decoupled from the user**:

```bash
python test_code/encoder.py          # prints raw and normalised knee angle
python test_code/motor_direction.py  # f / b / s / q to move the motor
python test_code/pid_control.py      # runs the PID loop to a fixed target
```

### Encoder calibration

The knee angle runs from **0° (fully extended) to 85° (flexed)**. `leg/models/motor_pid.py` maps the raw AS5600 angle linearly, using two calibration points:

```python
ESTIRADA = 235   # raw encoder angle (deg) with the knee fully extended
CONTRAIDA = 170  # raw encoder angle (deg) at 90° of knee flexion
```

Move the knee by hand to full extension and then to 90° flexion (measure with a goniometer), read the `raw:` value from `test_code/encoder.py` at each position, and put those numbers into `motor_pid.py`. The controller never commands more than 85°. The raw range must not cross the encoder's 0°/360° wrap point; rotate the magnet if it does.

## 6. Optional: Docker for everything

`docker-compose.cyton.yml` runs the broker, the OpenBCI stream and the inference as containers. `docker/Dockerfile.cyton` expects the BrainFlow source as `brainflow/master.zip` in the build context (download it from GitHub). The inference container copies `model.pkl` from `software/` at build time, so rebuild the image after retraining.

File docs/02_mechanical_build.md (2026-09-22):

# 2. Mechanical build

The add-on is a linear actuator mounted **in parallel** with the passive knee. A ball screw joins a point fixed to the thigh side of the 3R15 (**A**) to a point fixed to the shank (**B**). When the screw gets longer the knee extends, and when it gets shorter the knee flexes. The knee, socket, alignment and load path are left untouched, so the module can be removed and the user gets their passive prosthesis back.

Overview

## Geometry

Coordinates are measured from the knee centre **K** in the sagittal plane (mm):

| Symbol | Value | Meaning |
|---|---|---|
| a1 | 90 | Thigh attachment A, vertical distance above K |
| a2 | 50 | Thigh attachment A, horizontal offset |
| k1 | 295 | Shank attachment B, vertical distance below K (280 + 15) |
| k2 | 50 | Shank attachment B, horizontal offset |
| screw length | 384 mm at 1° flexion → 294 mm at 64° | Travel used for walking |

With these dimensions the knee reaches 0° (full extension) at 385 mm and about 75° flexion at 275 mm.

The moment arm of the screw about the knee is

```
r⊥ = |x_A·y_B − y_A·x_B| / |AB|
```

and the knee torque is `τ_K = F · r⊥`, where `F = 2π·τ_motor·η_screw / L`.

`hardware/mechanical/sizing/torque_calculation.py` reproduces Table 1 of the paper:

| Knee angle | Screw length | Motor torque needed for 44.3 N·m at the knee |
|---|---|---|
| 1° | 384 mm | 1.53 N·m |
| 5° | 380 mm | 1.40 N·m |
| 37.4° | 339 mm | 0.89 N·m |
| 64.1° | 294 mm | 0.77 N·m |

The load case is 0.49 N·m/kg (peak extension moment in level walking) × 90.36 kg (user + prosthesis). If you change the attachment points, edit the constants at the top of the script and re-run it to check your motor.

## Parts

| File | Part | Suggested process |
|---|---|---|
| `cad/step/motor_adapter.step` | Motor flange / shaft adapter | CNC, aluminium 6061 |
| `cad/step/ballscrew_nut_adapter.step`, `cad/stl/ballscrew_nut_adapter.stl` | Adapter from the SFU1610 flange nut to the thigh-side attachment | CNC, aluminium or steel |
| `cad/stl/rail_connector.stl` | Rail / screw connector | CNC or 3D print (check the loads) |
| `cad/step/D2.step`, `D3.step`, `D3_v2.step` | Brackets (D3 v2 supersedes D3) | CNC, aluminium |
| `cad/stl/electronics_box.stl` | Housing for the Raspberry Pi and E-stop, mounted below the socket | FDM, PETG |
| `cad/inventor/*` | Autodesk Inventor sources for the electronics box (2025 revision) | — |

Renders are in `hardware/mechanical/renders/`. The Inventor assembly `raspi.iam` references the vendor models of the Raspberry Pi 4, the 626-2Z bearing and the LAY37 button. Those are not redistributed here; download them from the vendors or replace them in the assembly.

## Assembly sequence

1. **Strip the host prosthesis** down to the 3R15 knee plus its upper and lower tubes. Record the alignment (tube lengths, clamp rotations) so it can be restored exactly.
2. **Motor end (shank side).** Bolt the motor adapter and the BK12 fixed support to the lower tube. The BK12 takes the axial load, so it must sit at the motor end. Couple the motor output shaft to the screw with the set-screw coupling. Tighten the set screw on a flat and secure it with threadlocker.
3. **Free end (thigh side).** Mount the BF12 floating support. Fix the ball-screw nut to the nut adapter, and fix that to the thigh-side attachment (point A) on the upper stem.
4. **Check the range by hand** before powering anything. Turn the screw to run the knee from full extension to at least 85° flexion. Nothing may collide, and the screw must not bottom out on the nut at either end. Measure the screw length at full extension and at full flexion.
5. **Mount the AS5600 encoder** on the knee axis, or on an external arm linking the upper and lower stems, with the diametric magnet centred on the sensor at the gap recommended in its datasheet (about 0.5–3 mm).
6. **Mount the electronics box** below the socket (the white box in the photo) and route the cables along the tubes with strain relief. The battery and PDB enclosure goes on the lateral side of the shank.
7. **Restore the original alignment** with the prosthetist. The module adds about 4 kg, mostly distal. Check it with the user standing, before any powered test.

> [!IMPORTANT]
> The worm gear cannot be back-driven. Once the motor is mounted **the user can no longer swing the shank freely**, and the knee holds whatever angle it was last driven to, even with the E-stop pressed. Plan the first powered tests with the prosthesis off the user (see [08](08_safety.md)).

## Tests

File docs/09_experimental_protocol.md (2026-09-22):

# 9. Experimental protocol (metabolic evaluation)

This is the protocol used in the paper to compare the energy cost of walking with **bilateral crutches**, the participant's **passive prosthesis** and the **active prosthesis**. It needs ethics-committee approval and informed consent.

## Equipment

- Indirect calorimetry: COSMED Q-NRG Max (breath-by-breath, exported as 30 s averages)
- Heart-rate chest strap synchronised with the metabolic monitor
- Motorised treadmill with lateral handrails (Lode Valiant Sport in the paper)

## Resting measurement (once, at the start of session 1)

- Overnight fast of at least 8 h; no caffeine from the previous evening.
- The participant removes the prosthesis and lies supine for **30 min** in a quiet, darkened room. Record gas exchange throughout.
- Use the window from 2 to 28 min as the resting metabolic rate.

## Each session (3 sessions)

1. **Standing baseline:** 10 min on the treadmill without the prosthesis, holding the handrails.
2. **Three walking conditions, 10 min each at 1 km/h**, with 3 min of seated rest between them (used to swap and check the prosthesis):
   - Crutches: no prosthesis, both crutches
   - Passive prosthesis (handrails allowed)
   - Active prosthesis in gait-pattern mode (handrails allowed)
3. Rotate the order across sessions to limit order effects:
   - Session 1: crutches → passive → active
   - Session 2: passive → active → crutches
   - Session 3: active → crutches → passive

## Analysis

`analysis/metabolic_analysis.ipynb` reads the COSMED exports and produces the figures below.

- Put `ses_1.xlsx`, `ses_2.xlsx`, `ses_3.xlsx` and `ree.xlsx` in `analysis/data/`.
- Each session file needs a `Fase` column labelling the phases: `parado` (standing), `bastones` (crutches), `pasiva`, `activa`.
- For each phase, the last minute (2 × 30 s rows) is taken as steady state.
- Energy expenditure (`EEkc`, kcal/day) and heart rate are reported pooled over the sessions, and also normalised to the **same session's** standing mean. Normalising removes the drift in baseline between sessions.

With a single participant, report results descriptively (mean ± SD) without inferential statistics.

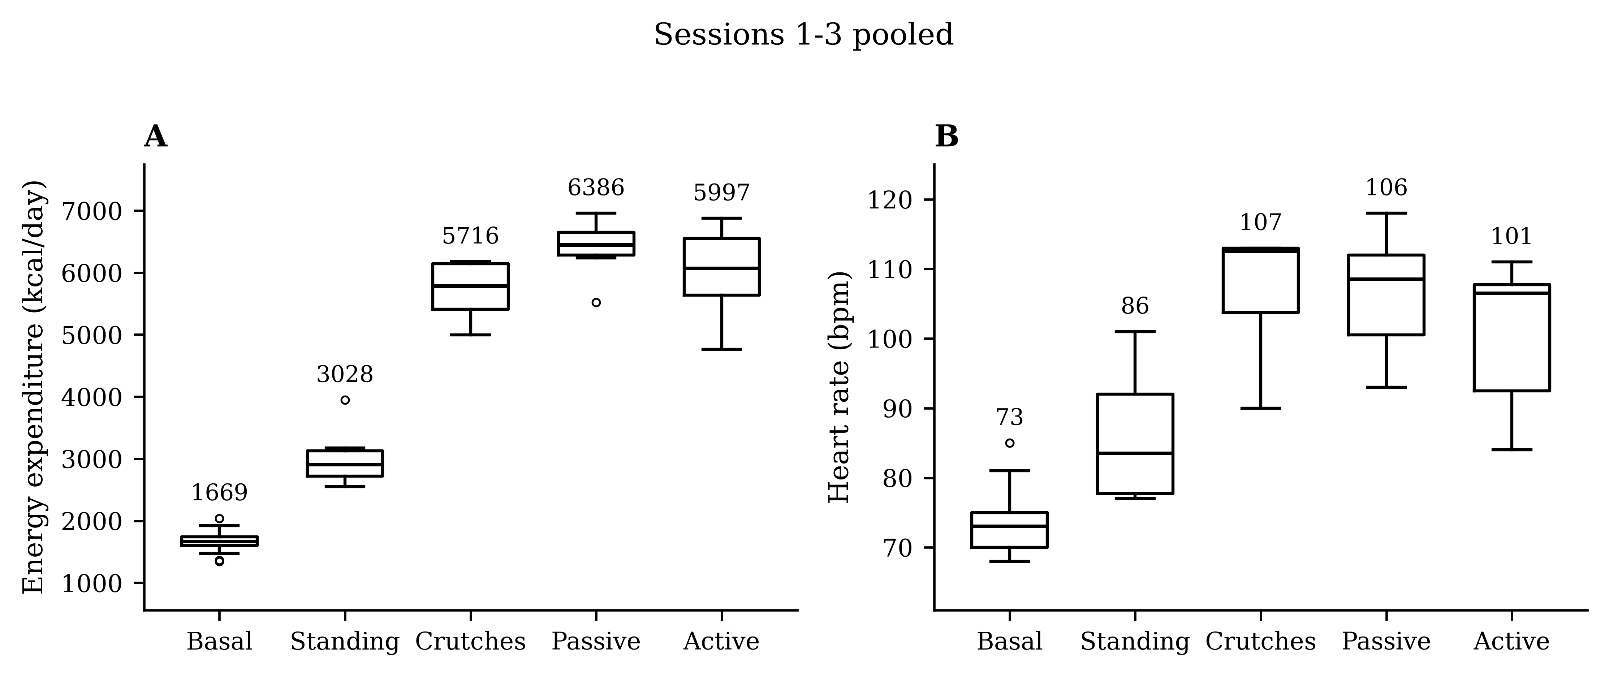
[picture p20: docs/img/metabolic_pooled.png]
Pooled

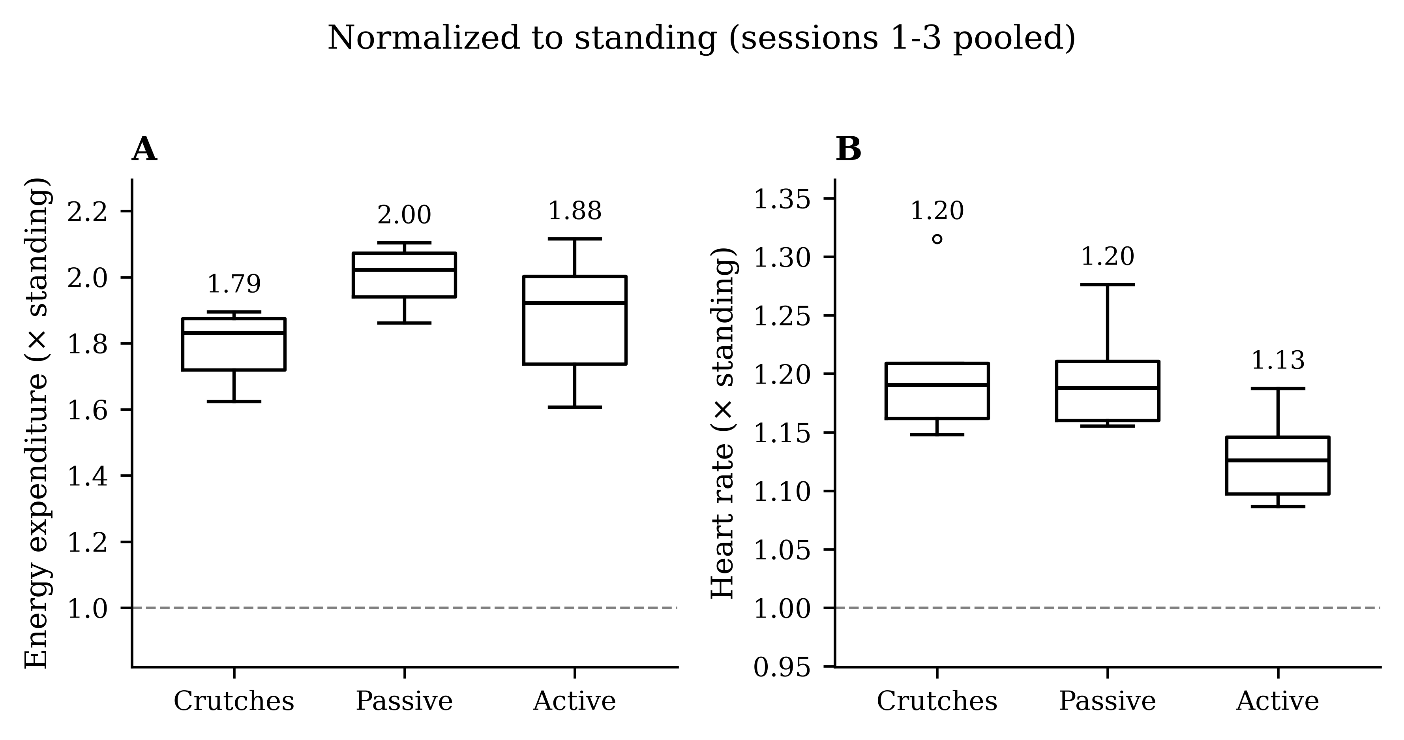
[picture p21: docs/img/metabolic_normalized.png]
Normalised


## EMG training protocol

See [06](06_training.md). It ran before every control session.

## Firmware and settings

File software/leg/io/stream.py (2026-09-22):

import os; os.system('clear')
import argparse
import logging
from brainflow.board_shim import BoardShim, BrainFlowInputParams, BoardIds
import time
from paho.mqtt import client as mqtt_client
import leg.parameters as p
import serial
import sys
import glob
from pprint import pprint
from leg.aux_tools import Buffer
import numpy as np
from time import sleep

# Import SciPy signal processing functions
from scipy.signal import iirnotch, butter, sosfilt, tf2sos

def create_channel_setting_command(channel, power_down, gain_set, input_type_set, bias_set, srb2_set, srb1_set, daisy_module=False):
    """
    Generate the channel setting command string.
    """
    if not (1 <= channel <= 16):
        raise ValueError("Channel must be between 1 and 16.")
    
    # Determine channel letter/number based on board or daisy module
    if channel <= 8:
        channel_str = str(channel)
    else:
        channel_str = chr(ord('Q') + (channel - 9))  # 'Q' to 'I' for daisy module channels

    # Construct the command string
    command = f"x{channel_str}{power_down}{gain_set}{input_type_set}{bias_set}{srb2_set}{srb1_set}x"

    return command

def find_openbci():
    """ Lists serial port names """
    if sys.platform.startswith('win'):
        ports = ['COM%s' % (i + 1) for i in range(256)]
    elif sys.platform.startswith('linux') or sys.platform.startswith('cygwin'):
        # Exclude current terminal "/dev/tty"
        ports = glob.glob('/dev/tty[A-Za-z]*')
    elif sys.platform.startswith('darwin'):
        ports = glob.glob('/dev/cu.*')
    else:
        raise EnvironmentError('Unsupported platform')

    result = []
    for port in ports:
        try:
            s = serial.Serial(port)
            s.close()
            result.append(port)
        except (OSError, serial.SerialException):
            pass
    open_bci_ports = [port for port in result if 'usb' in port.lower()]
    print(f"OpenBCI en puerto: {open_bci_ports}")
    
    #open_bci_ports = ['/dev/ttyAMA1']

    assert len(open_bci_ports) > 0, 'No se encontraron dispositivos OpenBCI'
    assert len(open_bci_ports) == 1, 'Se encontraron varios dispositivos OpenBCI'

    print(f"OpenBCI en puerto {open_bci_ports[0]}")

    return open_bci_ports[0]

class Publish:
    def __init__(self, board_shim):
        self.board_id = board_shim.get_board_id()
        self.board_shim = board_shim
        self.exg_channels = BoardShim.get_exg_channels(self.board_id)
        self.sampling_rate = BoardShim.get_sampling_rate(self.board_id)
        self.update_speed_ms = 50
        self.window_size = 5
        self.num_points = self.window_size * self.sampling_rate

        self.marker = -1
        self.buffer = Buffer(self.window_size, roll=True)


        # Initialize filters using SciPy
        self.mains = 50  # Notch filter frequency (Hz)
        self.band_low = 20  # Lower cutoff frequency for band-pass filter (Hz)
        self.band_high = 120  # Upper cutoff frequency for band-pass filter (Hz)

        # Design notch filter
        b_notch, a_notch = iirnotch(w0=self.mains / (self.sampling_rate / 2), Q=30)
        self.sos_notch = tf2sos(b_notch, a_notch)

        # Design band-pass filter
        self.sos_bp = butter(
            N=4,
            Wn=[self.band_low / (self.sampling_rate / 2), self.band_high / (self.sampling_rate / 2)],
            btype='bandpass',
            output='sos'
        )

        # Initialize filter states for each EEG channel
        self.num_eeg_channels = len(self.exg_channels)
        self.zi_bp = []
        self.zi_notch = []
        for _ in range(self.num_eeg_channels):
            self.zi_bp.append(np.zeros((self.sos_bp.shape[0], 2)))
            self.zi_notch.append(np.zeros((self.sos_notch.shape[0], 2)))

        # MQTT
        self.broker = p.BROKER_HOST
        self.port = p.BROKER_PORT
        self.topic = 'data'
        self.client = mqtt_client.Client(mqtt_client.CallbackAPIVersion.VERSION2, client_id='openbci')
        self.client.on_connect = on_connect
        self.client.on_message = self.on_message

        self.client.connect(self.broker, self.port)
        self.client.subscribe('marker')  # Subscribe to marker topic

        self.client.loop_start()

        self.update()
        self.client.loop_stop()

    def on_message(self, client, userdata, msg):
        self.marker = int(msg.payload.decode('utf-8'))

    def update(self):
        target_set = set(list(range(256)))
        start_time = None
        packaquete_loss_count= 0 
        prev_packaquete_loss_count = 0
        while True:
            time.sleep(8 / self.sampling_rate)  # Wait for at least 2 samples
            data = self.board_shim.get_board_data(self.num_points)  # np.float64 default
            if data.shape[1] == 0:
                continue

            if start_time is None:
                start_time = data[p.TIME_CHANNEL, 0]
            data[p.TIME_CHANNEL, :] -= start_time

            if self.marker != -1:
                data[p.MARKER_CHANNEL, :] = self.marker
            data = data[p.ALL_CHANNELS, :]

            # Apply filters to EEG channels
            for idx, channel in enumerate(range(8)):
                # Get data for this channel
                channel_data = data[channel, :] - 2250

                # Apply the band-pass filter with state
                filtered_bp, self.zi_bp[idx] = sosfilt(
                    self.sos_bp, channel_data, zi=self.zi_bp[idx]
                )

                # Apply the notch filter with state
                filtered_data, self.zi_notch[idx] = sosfilt(
                    self.sos_notch, filtered_bp, zi=self.zi_notch[idx]
                )

                # Assign filtered data back to data array
                data[channel, :] = filtered_data

            # Convert data to desired precision and publish
            data = data.astype(p.PRECISION)
            #print(data.shape)
            data_bytes = data.tobytes()

            #print(data[12, :][:20])
            paquetes = np.diff(data[12, :])

            if np.sum(paquetes) == 0 and len(data[12, :]) > 10:
                print("Reiniciando")
                prev_packaquete_loss_count = packaquete_loss_count
                packaquete_loss_count += 1

                if packaquete_loss_count >= 20:
                    self.board_shim.release_session()
                    self.board_shim.prepare_session()
                    self.board_shim.start_stream()

            if prev_packaquete_loss_count == packaquete_loss_count:
                packaquete_loss_count = 0

            self.client.publish(self.topic, data_bytes, qos=0)

def on_connect(client, userdata, flags, rc, properties):
    print(f"Connected with result code {rc}")

def main():
    BoardShim.enable_dev_board_logger()
    logging.basicConfig(level=logging.DEBUG)

    parser = argparse.ArgumentParser()
    # Use docs to check which parameters are required for specific board, e.g., for Cyton - set serial port
    parser.add_argument('--timeout', type=int, help='timeout for device discovery or connection', required=False,
                        default=0)
    parser.add_argument('--ip-port', type=int, help='ip port', required=False, default=0)
    parser.add_argument('--ip-protocol', type=int, help='ip protocol, check IpProtocolType enum', required=False,
                        default=0)
    parser.add_argument('--ip-address', type=str, help='ip address', required=False, default='')
    parser.add_argument('--mac-address', type=str, help='mac address', required=False, default='')
    parser.add_argument('--other-info', type=str, help='other info', required=False, default='')
    parser.add_argument('--streamer-params', type=str, help='streamer params', required=False, default='streaming_board://225.1.1.1:6677')
    parser.add_argument('--serial-port', type=str, help='OpenBCI dongle port (auto-detected if omitted)', required=False,
                        default='')
    parser.add_argument('--serial-number', type=str, help='serial number', required=False, default='')
    parser.add_argument('--board-id', type=int, help='board id, check docs to get a list of supported boards',
                        required=False, default=BoardIds.CYTON_BOARD)
    parser.add_argument('--file', type=str, help='file', required=False, default='')
    parser.add_argument('--master-board', type=int, help='master board id for streaming and playback boards',
                        required=False, default=BoardIds.CYTON_BOARD)
    args = parser.parse_args()

    params = BrainFlowInputParams()
    params.ip_port = args.ip_port
    params.serial_port = args.serial_port or find_openbci()
    params.mac_address = args.mac_address
    params.other_info = args.other_info
    params.serial_number = args.serial_number
    params.ip_address = args.ip_address
    params.ip_protocol = args.ip_protocol
    params.timeout = args.timeout
    params.file = args.file
    params.master_board = args.master_board
    #params.ip_address_aux = "225.1.1.2"
    #params.ip_port_aux = 6678

    board_shim = BoardShim(args.board_id, params)

    try:
        board_shim.prepare_session()
        # Configure OpenBCI
        # x (CHANNEL, POWER_DOWN, GAIN_SET, INPUT_TYPE_SET, BIAS_SET, SRB2_SET, SRB1_SET) X
        for i in range(1, 9):
            ch = create_channel_setting_command(channel=i,
                                                power_down= 0 if i >4 else 1,
                                                gain_set=6,
                                                input_type_set=0,
                                                bias_set=1,
                                                srb2_set=0,  # bipolar: each muscle on its own N/P pair
                                                srb1_set=0)
            

            board_shim.config_board(ch)
            sleep(0.1)

        #board_shim.add_streamer(args.streamer_params)
        
        board_shim.start_stream()
        Publish(board_shim)
    except BaseException:
        logging.warning('Exception', exc_info=True)
    finally:
        logging.info('End')
        if board_shim.is_prepared():
            logging.info('Releasing session')
            board_shim.release_session()

if __name__ == '__main__':
    board_id = BoardIds.CYTON_BOARD.value
    pprint(BoardShim.get_board_descr(board_id))

    main()

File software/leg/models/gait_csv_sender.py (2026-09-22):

import os; os.system('clear')
import time
import numpy as np
import pandas as pd
from paho.mqtt import client as mqtt_client
from leg.models.motor_pid import MotorPIDController
import leg.parameters as p


broker = p.BROKER_HOST
port = 1883
topic = "data"

CSV_PATH = os.path.join(os.path.dirname(__file__), '..', '..', 'knee_angle_gait_short.csv')


def on_connect(client, userdata, flags, rc, properties):
    print(f"Connected with result code {rc}")


def downsample(angles, n_samples):
    """Resample the angle curve to n_samples points, evenly spaced over the cycle."""
    x_old = np.linspace(0, 1, len(angles))
    x_new = np.linspace(0, 1, n_samples)
    return np.interp(x_new, x_old, angles).tolist()


def send_angles(csv_path=CSV_PATH, speed=1.0, loop=True, motor_control=True, n_samples=None,
                log_path=None):
    """Publish the angles in csv_path to the 'marker' topic, in order,
    and drive the knee motor to each angle via the PID controller.

    speed: playback speed multiplier (2.0 = twice as fast, 0.5 = half speed).
    loop: if True, repeat the gait cycle forever.
    motor_control: if True, drive the physical motor via MotorPIDController.
    n_samples: if set, downsample the angle curve to this many evenly-spaced points.
    log_path: if set, save (time, target_angle, current_angle) to this CSV on exit.
    """
    df = pd.read_csv(csv_path)
    angles = df['angle'].tolist()

    if n_samples is not None:
        angles = downsample(angles, n_samples)

    dt = 1.0 / (10 * speed)  # base rate of 10 Hz, scaled by speed

    client = mqtt_client.Client(mqtt_client.CallbackAPIVersion.VERSION2, 'gait_csv_sender')
    client.on_connect = on_connect
    client.connect(broker, port)
    client.loop_start()

    motor = MotorPIDController() if motor_control else None
    log = []
    t_start = time.time()

    print(f"Sending {len(angles)} angles at speed={speed} ({dt * 1000:.1f} ms/step)")

    try:
        while True:
            for angle in angles:
                angle -= 7
                print(angle)
                client.publish('marker', int(angle), qos=0)
                if motor is not None:
                    motor.target = angle
                if log_path is not None:
                    log.append((time.time() - t_start, angle,
                                 motor.current if motor is not None else None))
                time.sleep(dt)
            time.sleep(1.5)
            if not loop:
                break
    except KeyboardInterrupt:
        motor.target = 0
        client.publish('marker', 0, qos=0)
        time.sleep(0.1)  # give the publish time to go out before disconnecting
    finally:
        if motor is not None:
            motor.stop()
        client.loop_stop()
        client.disconnect()
        if log_path is not None:
            pd.DataFrame(log, columns=['time', 'target_angle', 'current_angle']).to_csv(
                log_path, index=False)
            print(f"Saved {len(log)} target/current angle samples to {log_path}")


if __name__ == '__main__':
    import argparse

    parser = argparse.ArgumentParser()
    parser.add_argument('--speed', type=float, default=0.1, help='Playback speed multiplier')
    parser.add_argument('--csv', type=str, default=CSV_PATH, help='Path to angle csv file')
    parser.add_argument('--no-loop', action='store_true', help='Send the cycle once and stop')
    parser.add_argument('--debug', action='store_true', help='Disable motor control')
    parser.add_argument('--n-samples', type=int, default=5,
                         help='Downsample the angle curve to N evenly-spaced samples')
    parser.add_argument('--log-csv', type=str, default=None,
                         help='Save target vs. current angle over time to this CSV')
    args = parser.parse_args()

    send_angles(csv_path=args.csv, speed=args.speed, loop=not args.no_loop,
                motor_control=not args.debug, n_samples=args.n_samples,
                log_path=args.log_csv)

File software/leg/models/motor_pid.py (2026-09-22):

import time
from threading import Thread

DEVICE_AS5600 = 0x36
IN1 = 13
IN2 = 18
FREQ = 20000
MIN_SPEED = 100

ESTIRADA = 235   # fully extended raw angle
CONTRAIDA = 170  # fully contracted raw angle
ANGLE_MAX = 90   # degrees, fully contracted


def _clamp(x, lo=0.0, hi=1.0):
    return lo if x < lo else hi if x > hi else x


class PID:
    def __init__(self, kp, ki, kd, integral_limit=100.0):
        self.kp = kp
        self.ki = ki
        self.kd = kd
        self.integral_limit = integral_limit
        self._integral = 0.0
        self._prev_error = None

    def reset(self):
        self._integral = 0.0
        self._prev_error = None

    def compute(self, error, dt):
        self._integral = max(-self.integral_limit,
                             min(self.integral_limit, self._integral + error * dt))
        derivative = ((error - self._prev_error) / dt
                      if self._prev_error is not None and dt > 0 else 0.0)
        self._prev_error = error
        return self.kp * error + self.ki * self._integral + self.kd * derivative


class MotorPIDController:

    def __init__(self, kp=10.0, ki=0.1, kd=0.15, dt=0.01):
        import RPi.GPIO as GPIO
        from smbus2 import SMBus

        self._GPIO = GPIO
        self._bus = SMBus(1)

        GPIO.setmode(GPIO.BCM)
        GPIO.setup(IN1, GPIO.OUT)
        GPIO.setup(IN2, GPIO.OUT)
        self._pwm1 = GPIO.PWM(IN1, FREQ)
        self._pwm2 = GPIO.PWM(IN2, FREQ)
        self._pwm1.start(0)
        self._pwm2.start(0)

        self._target = self._read_angle()
        self._current = self._target
        self._pid = PID(kp, ki, kd)
        self._dt = dt
        self._running = True

        thread = Thread(target=self._loop, daemon=True)
        thread.start()

    def _read_angle(self):
        """Return knee angle in degrees [0, 90] (0 = fully extended, 90 = fully contracted)."""
        data = self._bus.read_i2c_block_data(DEVICE_AS5600, 0x0C, 2)
        raw = (data[0] << 8) | data[1]
        raw_deg = raw * 360.0 / 4096.0
        return _clamp((raw_deg - ESTIRADA) / (CONTRAIDA - ESTIRADA)) * ANGLE_MAX

    @staticmethod
    def _angle_error(target, current):
        """Signed error in degrees. Range is linear [0, 90] so no wraparound needed."""
        return target - current

    def _drive(self, output):
        output = max(-100.0, min(100.0, output))
        if abs(output) < 1.0:
            self._pwm1.ChangeDutyCycle(0)
            self._pwm2.ChangeDutyCycle(0)
            return
        speed = max(MIN_SPEED, abs(output))
        if output > 0:
            self._pwm1.ChangeDutyCycle(0)
            self._pwm2.ChangeDutyCycle(speed)
        else:
            self._pwm1.ChangeDutyCycle(speed)
            self._pwm2.ChangeDutyCycle(0)

    def _stop(self):
        self._pwm1.ChangeDutyCycle(0)
        self._pwm2.ChangeDutyCycle(0)

    @property
    def target(self):
        return self._target

    @target.setter
    def target(self, value):
        self._target = float(value)

    @property
    def current(self):
        """Last angle read by the control loop, in degrees [0, 90]."""
        return self._current

    def _loop(self):
        t_prev = time.time()
        while self._running:
            t_now = time.time()
            loop_dt = t_now - t_prev
            if loop_dt < self._dt:
                time.sleep(self._dt - loop_dt)
                continue
            current = self._read_angle()
            self._current = current
            error = self._angle_error(self._target, current)
            output = self._pid.compute(error, loop_dt)
            self._drive(output)
            print(f'target: {self._target:.1f}°  current: {current:.1f}°  '
                  f'error: {error:+.1f}°  output: {output:+.1f}')
            t_prev = t_now

    def stop(self):
        self._running = False
        self._stop()
        self._pwm1.stop()
        self._pwm2.stop()
        self._GPIO.cleanup()
